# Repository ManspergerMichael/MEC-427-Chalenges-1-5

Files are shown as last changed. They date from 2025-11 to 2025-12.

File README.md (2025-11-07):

# MEC 427 — Smart Sensor and Actuator System (Challenges 1–3)

This repository contains the work for MEC 427 Smart Systems Challenges 1–3 using an Adafruit Circuit Playground Express (CPX) with CircuitPython. For the full design and schedule, see `Ch1,2,3/CombinedSmartSystemPlan.markdown`.

## Objective

Build and demonstrate a fluid control system using a 6-inch PVC end-cap tank suspended on a PVC tripod. Detect water level in a lower container using three CPX capacitive touch sensors (alligator clips) with a majority-vote scheme, and drive a 3D‑printed tube‑pinch valve using a TowerPro SG92R servo to prevent overflow.

## Challenge 1 — Fluid Level Sensor (Capacitive)

- **Location**: `Challenge_1/code.py`
- Use CPX capacitive touch (`touchio.TouchIn`) on A1 to sense water presence via an alligator-clip probe.
- Includes on-device visual calibration UI (NeoPixel bar + threshold marker) and saves threshold to `cal.txt`.
- Goal: Reliably detect when water reaches the probe depth.

## Challenge 2 — Voting Sensor System (Redundancy)

- **Location**: `Challenge_2/code.py`
- Expand to three probes on pads A1–A3, positioned at similar heights.
- Implement majority voting: "level reached" when ≥2 sensors exceed the threshold.
- Goal: Robust detection that tolerates a single sensor fault or noise.

## Challenge 3 — Smart Actuator System (Pinch Valve)

- 3D‑print a pinch‑valve mechanism and mount an SG92R servo to pinch 1/4" tubing.
- Wire servo: signal → A6, power → VOUT, ground → GND.
- Logic: On “level reached,” set `servo.angle = 90` to close the valve; provide a button (e.g., `button_a`) action to reset/open.

---

For detailed build notes, materials, timeline, and risks, see `Ch1,2,3/CombinedSmartSystemPlan.markdown`. The CPX runtime code lives in `Challenge_1/code.py`.

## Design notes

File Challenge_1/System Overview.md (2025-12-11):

# System Overview

## Introduction

The Liquid Level Sensor System is a mechatronics training platform designed to demonstrate the integration of sensors, controls, and user calibration in a process environment. Its primary function is to detect the liquid level in a container of water and provide visual feedback through onboard indicators.

## Hardware Architecture

The system is built around the **Adafruit Circuit Playground Express (CPX)**, which serves as the central controller. The CPX utilizes its capacitive touch sensor at pin **A1**, connected via a wired alligator clip secured to the rim of the container, to detect changes in capacitance caused by the presence of liquid. This sensing method allows the system to identify when the liquid reaches a defined level.d level.

## Power and Feedback

Power is supplied by a **3.7V battery**, ensuring portability and safe operation in laboratory settings. The CPX's **NeoPixel LEDs** provide real-time feedback and are also used during manual calibration. Calibration enables adjustment for environmental conditions (humidity, temperature, container material) and for different liquids with varying dielectric properties, ensuring reliable detection across multiple scenarios.enarios.

## System Integration

This system highlights the integration of hardware (CPX, sensors, battery), software (calibration routines, LED control), and process control concepts. It serves as a practical demonstration of how mechatronic systems combine sensing, computation, and actuation to achieve robust functionality in real-world applications.

---
## Sequential Function Chart

Controller Overview
The Adafruit Circuit Playground Express (CPX) serves as the central controller for the Liquid Level Sensor System. It integrates sensing, computation, and user interface functions into a single compact platform, enabling reliable detection and calibration of liquid levels.
The CPX is powered by a 3.7V rechargeable battery, providing portable operation and safe voltage levels for laboratory use. Its capacitive touch sensor at pin A1 is configured as the primary input, connected via an alligator clip to the rim of the container. This sensor detects changes in capacitance caused by the presence of liquid, allowing the controller to determine when the water reaches the defined level.
The CPX also incorporates NeoPixel LEDs and onboard controls, which serve as both output indicators and calibration tools. The LEDs provide immediate visual feedback of sensor status, while the onboard buttons allow manual adjustment of sensitivity to account for environmental conditions (humidity, temperature, container material) and variations in liquid properties. This ensures accurate and adaptable operation across different scenarios.
Internally, the CPX executes a control program written in CircuitPython which manages sensor input, calibration routines, and output display. The program is modular, allowing easy modification for expanded functionality, such as multi-level detection or integration with external actuators.
By combining sensing, processing, and feedback in one device, the CPX demonstrates the principles of mechatronic control: integration of hardware, software, and user interaction to achieve robust system performance.

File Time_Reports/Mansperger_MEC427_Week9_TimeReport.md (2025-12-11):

# 🛠️ MEC 427 Advanced Sensors and Actuators Challenges 1-5

---

## 📅 Date & Time
- **Report Date:** `12-01-2025`
- **Time Block:** `12-01 – 12-06`
- **Time Spent This Session:** `12 hours / 0 minutes`
- **Cumulative Time on Project:** `45 hours / 30 minutes`

---

## 📂 Project Overview
- **Project Title:**  `Challenge 4: Cable trolly, and Challenge 3: Water control system.`
- **Project Objective(s):**  
- `Design an actuator system that can traverse a steel tension cable. `
- **Current Phase:** `Completion`

---

## 🔧 Task / Activity Details
- **Module / Subsystem:**  `Challenge 4 Gantry motion control system Wiring and model design refinement`
- **Specific Task or Activity:**  
- **Time Spent on This Task:** `6 hours /  minutes`
- **% of Total Time:** `80%`
- **Resources Used:**  
  - **Hardware:**  
  - **Software:**  
  - **Tools:**  `Grok AI, Fusion 360.`
  - **Documentation:**  `Design Sketches CAD designs`
---
- **Module / Subsystem:**  `Challenge 3 Water control system coding and testing`
- **Specific Task or Activity:**  
- **Time Spent on This Task:** `2 hours / 30 minutes`
- **% of Total Time:** `50%`
- **Resources Used:**  
  - **Hardware:**  `Adafruit CPX, capacitive touch sensors, servo pinch valve, water tower model.`
  - **Software:**  `VsCode, CircuitPython.`
  - **Tools:**  `Copilot AI`
  - **Documentation:**  ` AI conversation, code files, test results.`

- ## Project Status Update:
- **Task/Module:** `Challenge 4 Gantry motion control system design`
- **Project Completion Status:** `90% complete`
- **Milestones Reached:**  ``CAD Model Updated to final design, STL files generated for 3D printing.`
- **Blockers or Issues:**  `Delays in 3D printing due to printer availability.`
- 
- **Task/Module:** `Challenge 3 Water control system coding and testing`
- **Project Completion Status:** `100% complete`
- **Milestones Reached:**  `Fine tuned the system to reliably control water flow based on sensor input.`
- **Blockers or Issues:**  `Fine-tuning the sensor calibration to avoid false readings.`

## 📦 Results & Deliverables
- **What Was Achieved:**  `Completed Challenge 4 Wiring and finished challenge 3.`
- **Artifacts Created:**  `CAD designs for cable trolly system. Code and test results for water control system.`
- **Validation / Testing Outcomes:**  `Water tower actuation tests show reliable operation with current calibration.`
- **Changes Made to Design or Approach:**  `GroK AI was used to assist in design ideation and STL generation with tinkercad.`

---

## 📜 Narrative & Observations
> _Use this section for detailed descriptions, reflections, and context. Include technical notes, emotional observations, and rationale for decisions._

- **Narrative Summary:**  `Challenge 3 was completed with successful unit testing of the software and functionality of the water control system. Challenge 4 design was refined and wiring schematics were developed, but physical assembly is pending due to 3D printing delays. Thinking of my workflow I can see the 'hobbyist' side of me wanting to get my hands on the physical parts. I did not spend enough time considering various aspects of system design. The carriage itself will work hypothetically,  things such as housing for electronics and the weight and distribution of components were not fully considered. Also I need to work on my documentation skills to better track changes and decisions made during the design process. Over the coming break I will go over my project assets and develop my overall workflow to be more efficient and effective.`

---

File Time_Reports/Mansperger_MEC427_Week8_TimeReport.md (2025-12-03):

# 🛠️ MEC 427 Advanced Sensors and Actuators Challenges 1-5

---

## 📅 Date & Time
- **Report Date:** `11-22-2025`
- **Time Block:** `11-17 – 11-22`
- **Time Spent This Session:** `8 hours / 30 minutes`
- **Cumulative Time on Project:** `33 hours / 30 minutes`

---

## 📂 Project Overview
- **Project Title:**  `Challenge 4: Cable trolly, and Challenge 3: Water control system.`
- **Project Objective(s):**  
- `Design an actuator system that can traverse a steel tension cable. `
- **Current Phase:** `Design Phase`

---

## 🔧 Task / Activity Details
- **Module / Subsystem:**  `Challenge 4 Gantry motion control system design`
- **Specific Task or Activity:**  
- **Time Spent on This Task:** `6 hours /  minutes`
- **% of Total Time:** `80%`
- **Resources Used:**  
  - **Hardware:**  
  - **Software:**  
  - **Tools:**  `Grok AI, Fusion 360.`
  - **Documentation:**  `Design Sketches CAD designs`
---
- **Module / Subsystem:**  `Challenge 3 Water control system coding and testing`
- **Specific Task or Activity:**  
- **Time Spent on This Task:** `2 hours / 30 minutes`
- **% of Total Time:** `50%`
- **Resources Used:**  
  - **Hardware:**  `Adafruit CPX, capacitive touch sensors, servo pinch valve, water tower model.`
  - **Software:**  `VsCode, CircuitPython.`
  - **Tools:**  `Copilot AI`
  - **Documentation:**  ` AI conversation.`

- ## Project Status Update:
- **Task/Module:** `Challenge 4 Gantry motion control system design`
- **Project Completion Status:** `75% complete`
- **Milestones Reached:**  `Finalized CAD design for gantry motion control system.`
- **Blockers or Issues:**  
- 
- **Task/Module:** `Challenge 3 Water control system coding and testing`
- **Project Completion Status:** `8% complete`
- **Milestones Reached:**  `System is able to read water levels and actuate the valve based on sensor input.`
- **Blockers or Issues:**  `Fine-tuning the sensor calibration to avoid false readings.`

## 📦 Results & Deliverables
- **What Was Achieved:**  `Completed Challenge 4 Design and finished the first phase of coding for challenge 3.`
- **Artifacts Created:**  `CAD designs for cable trolly system. Code and test results for water control system.`
- **Validation / Testing Outcomes:**  `Water tower actuation tests show reliable operation with current calibration.`
- **Changes Made to Design or Approach:**  `GroK AI was used to assist in design ideation and STL generation with tinkercad.`

---

## 📜 Narrative & Observations
> _Use this section for detailed descriptions, reflections, and context. Include technical notes, emotional observations, and rationale for decisions._

- **Narrative Summary:**  `Challenge 4 required several more iterations of design before I settled on the 'sandwich' concept. Using Grok AI to brainstorm design ideas and Fusion 360 for CAD modeling greatly expedited the process. The idea didn't really come together until after researching cable and zipline systems in industry applications. For Challenge 3,I hit the limitations of the CPX memory when implementing more features. Copilot was able to streamline the code and reduce memory usage significantly. Encountered power spikes when the servo actuated, which I mitigated by adding a separate power supply for the servo. Learning a lot about electronics, wiring, and power management. My lack of experience in engineering is a recurring challenge, but I'm making progress.`

---

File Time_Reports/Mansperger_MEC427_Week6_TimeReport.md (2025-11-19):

# 🛠️ MEC 427 Advanced Sensors and Actuators Challenges 1-5

---

## 📅 Date & Time
- **Report Date:** `11-08-2025`
- **Time Block:** `11-03 – 11-08`
- **Time Spent This Session:** `7 hours / minutes`
- **Cumulative Time on Project:** `21 hours / 30 minutes`

---

## 📂 Project Overview
- **Project Title:**  `Challenges 1-3: Smart Sensor and Actuator System`
- **Project Objective:**  `Create a smart fluid control system using level sensors and a servo-actuated pinch valve to control flow.`
- **Current Phase:** `Implementation Phase`

---

## 🔧 Task / Activity Details
- **Module / Subsystem:**  `Voting sensor system.`
- **Specific Task or Activity:**  
- **Time Spent on This Task:** `7 hours / minutes`
- **% of Total Time:** `100%`
- **Resources Used:**  
  - **Hardware:**  `Adafruit Circuit Playground Express (CPX), TowerPro SG92R servo, alligator clips, 1/4" aquarium tubing, 3D printer (PLA filament)`
  - **Software:**  `CircuitPython, VSCode IDE`
  - **Tools:**  `Copilot/Claude AI, Internet Research, Python.`
  - **Documentation:**  `Code files.`

---

## 📈 Progress Tracking
- **Task/Module:** `Challenge 1`
- **Project Completion Status:** `100% complete`
- **Milestones Reached:**  `Completed fluid level sensor with capacitive touch.`
- **Blockers or Issues:**  `Learning about calibration.`
- 
**Task/Module:** `Challenge 2`
- **Project Completion Status:** `80% complete`
- **Milestones Reached:**  `Sensor array prototype completed.`
- **Blockers or Issues:**  `Need to adapt the tower to hold multiple sensors securely.`
---

## 📦 Results & Deliverables
- **What Was Achieved:**  `Completed Challenge 1 and made significant progress on Challenge 2.`
- **Artifacts Created:**  `CircuitPython code for Challenges 1 and 2, sensor array prototype.`
- **Validation / Testing Outcomes:**  `Sensor can detect water level`
- **Changes Made to Design or Approach:**  

---

## 📜 Narrative & Observations
> _Use this section for detailed descriptions, reflections, and context. Include technical notes, emotional observations, and rationale for decisions._

- **Narrative Summary:**  `I made good progress on the software for the sensor and actuator system. In challenge 1 I added a calibration UI to help set the capacitive threshold for water detection. I found I need to adapt the tower to hold multiple sensors securely for challenge 2. Alligator clips are proving to be difficult. I also need a new work area as my desk dosen't have enough space for the full setup. and my cables are too short to arrange everything properly.`
- **Technical Notes:**  
- **Lessons Learned / Insights:**  
- **Emotional/Workflow Reflections (optional):**  

---

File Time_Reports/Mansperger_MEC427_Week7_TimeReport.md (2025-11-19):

# 🛠️ MEC 427 Advanced Sensors and Actuators Challenges 1-5

---

## 📅 Date & Time
- **Report Date:** `11-15-2025`
- **Time Block:** `11-10 – 11-15`
- **Time Spent This Session:** `3 hours / 30 minutes`
- **Cumulative Time on Project:** `25 hours / 0 minutes`

---

## 📂 Project Overview
- **Project Title:**  `Challenges 4 & 5: Gantry motion control system and Bead Sorting without controls perspective.`
- **Project Objective(s):**  
- `Design an actuator system that can traverse a steel tension cable. `
- `Conseptualize a bead sorting system that uses sensors and actuators to sort beads without using a controls perspective.`
- **Current Phase:** `Implementation Phase`

---

## 🔧 Task / Activity Details
- **Module / Subsystem:**  `Challenge 4 Gantry motion control system design`
- **Specific Task or Activity:**  
- **Time Spent on This Task:** `1 hours / 30 minutes`
- **% of Total Time:** `50%`
- **Resources Used:**  
  - **Hardware:**  
  - **Software:**  
  - **Tools:**  `Grok AI, Tinkercad, Internet research.`
  - **Documentation:**  `Design Sketches and AI generated STL.`
---
- **Module / Subsystem:**  `Challenge 5 Bead Sorting without controls perspective`
- **Specific Task or Activity:**  
- **Time Spent on This Task:** `2 hours / 0 minutes`
- **% of Total Time:** `50%`
- **Resources Used:**  
  - **Hardware:**  
  - **Software:**  
  - **Tools:**  `Grok AI, Knowledge course resources, Internet research.`
  - **Documentation:**  `Notes, sketches, AI conversation.`

- ## Project Status Update:
- **Task/Module:** `Challenge 4 Gantry motion control system design`
- **Project Completion Status:** `70% complete`
- **Milestones Reached:**  `Completed a conceptual design and prototype for gantry motion control system.`
- **Blockers or Issues:**  `A dentist appointment caused me to miss a comp-team session`
- 
- **Task/Module:** `Challenge 5 Bead Sorting without controls perspective`
- **Project Completion Status:** `100% complete`
- **Milestones Reached:**  `Completed a conceptual design for bead sorting system.`
- **Blockers or Issues:**  `Not thinking about controls made it challenging to conceptualize the sorting mechanism.`

## 📦 Results & Deliverables
- **What Was Achieved:**  `Completed Challenge 5 and made significant progress on Challenge 4.`
- **Artifacts Created:**  `Conseptusual designs and AI generated STL files for gantry system. Sketches and notes for bead sorting system.`
- **Validation / Testing Outcomes:**  `N/A`
- **Changes Made to Design or Approach:**  `GroK AI was used to assist in design ideation and STL generation with tinkercad.`

---

## 📜 Narrative & Observations
> _Use this section for detailed descriptions, reflections, and context. Include technical notes, emotional observations, and rationale for decisions._

- **Narrative Summary:**  `Challenge 2: I didn't consider mounting the sensors on the water tower during my initial design, I compensated by using the CPX kit's alligator clips as extension wires and fixed them to the legs of the tower using tape. The sensor probes hang down into the lower container to detect water level. Callibration was a learning process, assisted by Copilot AI. The CPX capacitive touch sensors are rather sensitive and the wire insulation is suboptimal. An issue where the sensor readings would reverse polarity when the probes touched water was resolved by implementing a dual-threshold detection system, accounting for both increases and decreases in capacitance. This approach improved reliability significantly. The voting system was implemented successfully, allowing the system to function correctly even if one sensor failed or provided erroneous readings.`
- **Narrative Summary:**  `Challenge 4: I conceptualized a Tri-wheel gantry motion control system that uses a motor to move an actuator along a steel tension cable. I used Grok AI to generate design sketches and STL files for the gantry components. The design includes a motor, pulley system, and guide rails to ensure smooth movement along the cable.`
- - **Narrative Summary:**  `Challenge 5: A design session with Grok AI and my notes from the knowledge course. I conceptualized a bead sorting system where the blue and yellow beads sorted by color on a single track that splits into two paths. The beads pass through photoelectric sensors that detect their color. When a blue bead is detected, a small servo actuator diverts it to the left path, while yellow beads continue straight. This design avoids complex control systems by using simple sensor-actuator pairs for sorting. This consept can be scaled up to include more colors and sorting paths or multiple tracks for volume sorting.`

---

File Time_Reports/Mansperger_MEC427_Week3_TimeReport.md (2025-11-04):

# 🛠️ MEC 427 Advanced Sensors and Actuators Challenges 1-5

---

## 📅 Date & Time
- **Report Date:** `10-18-2025`
- **Time Block:** `10-13 – 10-18`
- **Time Spent This Session:** `5 hours / minutes`
- **Cumulative Time on Project:** `9 hours / minutes`

---

## 📂 Project Overview
- **Project Title:**  `MEC 427 Advanced Sensors and Actuators Challenges 1-5`
- **Project Objective:**  `Complete Challenges 1-5 for MEC 427 Advanced Sensors and Actuators course.`
- **Current Phase:** `Sketching and Planning Phase`

---

## 🔧 Task / Activity Details
- **Module / Subsystem:**  `Development Plans research and documentation`
- **Specific Task or Activity:**  `Planning and research for Challenges 1-5`
- **Time Spent on This Task:** `5 hours`
- **% of Total Time:** `100%`
- **Resources Used:**  
  - **Hardware:**  
  - **Software:**  
  - **Tools:**  `Internet resources, Grok AI, VScode, Markdown, Copilot`
  - **Documentation:**  

---

## 📈 Progress Tracking
- **Task/Module Completion Status:** `85% complete (estimated)`
- **Project Completion Status:** `15% complete (estimated)`
- **Milestones Reached:**  `Development Plans drafted for Challenges 1-5`
- **Blockers or Issues:**  
- **Next Steps / Planned Actions:**  `Build water tank prototype for Challenge 1-3, start developing code for CPX microcontroller, build water tower fixture.`

---

## 📦 Results & Deliverables
- **What Was Achieved:** `3 development plans drafted for Challenges 1-5`
- **Artifacts Created:**  `Development plan documents`
- **Validation / Testing Outcomes:**  
- **Changes Made to Design or Approach:**  

---

## 📜 Narrative & Observations
> _Use this section for detailed descriptions, reflections, and context. Include technical notes, emotional observations, and rationale for decisions._

- **Narrative Summary:** 
- `I reviewed my Adafruit CPX microcontroller kit and found that it came with all the necessary components to build a smart sensor/actuator system. I worked with Grok AI to brainstorm ideas for my system. I will be creating a water tower and container system were capacitive sensors will detect the water level in the container and a servo motor controlled pinch valve will stop the water flow when water reaches a certain level in the container. The water "tower" will be made of PVC pipes with rubber tubing fixed to a hole at the bottom of the tank. The pinch valve I can design with CAD or I could find an existing design I can modify and print. Construction of the tower should be simple. I set up a Python development environment using VSCode and installed the necessary libraries to program the CPX. I finished the initial development plans for Challenges 1-5, challenges 4 and 5 I will need to do more research/sketching on. I'll need to ask if a tension wire fixture will be provided making one might be an issue at home. The CPX has built in accelerometer I can use as a balance sensor. The actuator will need more thought.`
- **Technical Notes:** ''
- **Lessons Learned / Insights:** `Marveling a bit at how productive AI tools can be for brainstorming, planning, and documentation. Feeling optimistic about the project direction so far.`

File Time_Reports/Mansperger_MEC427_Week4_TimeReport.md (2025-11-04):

# 🛠️ MEC 427 Advanced Sensors and Actuators Challenges 1-5

---

## 📅 Date & Time
- **Report Date:** `10-25-2025`
- **Time Block:** `10-20 – 10-25`
- **Time Spent This Session:** `3 hours / 30 minutes`
- **Cumulative Time on Project:** `12 hours / 30 minutes`

---

## 📂 Project Overview
- **Project Title:**  `Challenge 1 - 3 Water Level Sensor and Actuator System`
- **Project Objective:**  `Assemble and program a water level sensor and actuator system using the Adafruit CPX microcontroller to control water flow based on sensor input.`
- **Current Phase:** `Setup Phase`

---

## 🔧 Task / Activity Details
- **Module / Subsystem:**  `Construction of water tower`
- **Specific Task or Activity:** `Assemble water tower structure using PVC pipes and rubber tubing` 
- **Time Spent on This Task:** `3 hours / 30 minutes`
- **% of Total Time:** `100%`
- **Resources Used:**  
  - **Hardware:**  `PVC pipe, rubber tubing, Adafruit CPX microcontroller, capasitive sensors, servo motor, 3D printed pinch valve`
  - **Software:**  
  - **Tools:**  `3D printer`
  - **Documentation:**  

---

## 📈 Progress Tracking
- **Task/Module Completion Status:** `e.g., 15% complete`
- **Project Completion Status:** `15% complete`
- **Milestones Reached:**  `Gatered all materials, assembled water tower structure`
- **Blockers or Issues:**  `Pinch valve design needs refinement to ensure proper sealing`
- **Next Steps / Planned Actions:**  `Refine pinch valve design and reprint, begin programming CPX microcontroller to read sensor data and control servo motor`

---

## 📦 Results & Deliverables
- **What Was Achieved:**  `Assembled the water tower and tested prototype of pinch valve`
- **Artifacts Created:**  `3D printed pinch valve prototype, water tower assembly`
- **Validation / Testing Outcomes:**  
- **Changes Made to Design or Approach:**  

---

## 📜 Narrative & Observations
> _Use this section for detailed descriptions, reflections, and context. Include technical notes, emotional observations, and rationale for decisions._

- **Narrative Summary:**  `Furstrated with the delay in needing to reprint the pinch valve. But the tower should work for my project. Hoped to get to programming this week. Will look over challenge 4 and 5 while waiting for the print to finish.`
- **Technical Notes:**  
- **Lessons Learned / Insights:**  
- **Emotional/Workflow Reflections (optional):**  

---

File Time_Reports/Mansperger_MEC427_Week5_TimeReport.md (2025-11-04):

# 🛠️ MEC 427 Advanced Sensors and Actuators Challenges 1-5

---

## 📅 Date & Time
- **Report Date:** `11-01-2025`
- **Time Block:** `10-27 – 11-01`
- **Time Spent This Session:** `2 hours / minutes`
- **Cumulative Time on Project:** `14 hours / 30 minutes`

---

## 📂 Project Overview
- **Project Title:**  `Challenge 4 - Development Plans for Advanced Sensors and Actuators`
- **Project Objective:**  `Create Initial Development Plans`
- **Current Phase:** `Sketching Phase`

---

## 🔧 Task / Activity Details
- **Module / Subsystem:**  `Development Plans`
- **Specific Task or Activity:**  
- **Time Spent on This Task:** `2 hours / minutes`
- **% of Total Time:** `100%`
- **Resources Used:**  
  - **Hardware:**  
  - **Software:**  
  - **Tools:**  `Grok AI, Internet Research`
  - **Documentation:**  `Concept sketches for actuator`

---

## 📈 Progress Tracking
- **Task/Module Completion Status:** `50% complete`
- **Project Completion Status:** `15% complete`
- **Milestones Reached:**  
- **Blockers or Issues:**  `Several internet services were down. Stopped by need of dentist appointment.`
- **Next Steps / Planned Actions:**  `Complete development plans and begin prototyping actuator designs.`

---

## 📦 Results & Deliverables
- **What Was Achieved:**  
- **Artifacts Created:**  `Concept sketches for actuator`
- **Validation / Testing Outcomes:**  
- **Changes Made to Design or Approach:**  

---

## 📜 Narrative & Observations
> _Use this section for detailed descriptions, reflections, and context. Include technical notes, emotional observations, and rationale for decisions._

- **Narrative Summary:**  `AWS and other internet services were down for much of the week, along with my sudden tooth pain that required a dentist visit. I was able to make some progress on the development plans. Next week I will aim to make up for lost time. 12 hours in lab work next week.`
- **Technical Notes:**  
- **Lessons Learned / Insights:**  
- **Emotional/Workflow Reflections (optional):**  

---

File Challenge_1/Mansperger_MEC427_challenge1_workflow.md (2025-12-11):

# Smart Sensor Development Workflow  
**Assignment: Challenge 1 – Smart Sensor**

---

## 1. Application Description  
The smart sensor system is designed to **detect when liquid reaches a predefined level in a container**.  

- **Function**: The sensor continuously monitors the liquid level and identifies when the set threshold is reached.  
- **Conditions**: Upon detecting liquid at the target level, the sensor outputs a **HIGH signal** to the microcontroller for processing.  
- **Feedback**: The system provides a clear indication (e.g., LED, buzzer, or digital flag) that the container has reached the fill level.  
  - **Conditions**: The system will continue sending a **HIGH signal** as long as liquid is detected at the sensor point.  

---

## 2. Task Description  
- Develop a sensor system capable of accurately detecting liquid levels.  
- Integrate the sensor with a **microcontroller** for real-time monitoring and data acquisition.  
- Implement calibration routines to account for different liquid properties (density, conductivity).  
- Provide user-defined alarms for high/low levels.  
- Validate performance through testing in simulated tank conditions.  

---

## 3. Focus Area  

### Work Piece  
A **water tower model** was chosen as the work piece to develop the fill sensor because its construction and function are simple and effective for demonstration. The setup consists of **two containers**, with one suspended above the other. A hose at the bottom of the top container allows water to flow downward, while sensors are mounted on the rim of the bottom container to detect the liquid level.  

### Mechanism  
The sensor is mounted on the lower container and wired directly to a **microcontroller** for real-time monitoring.  
- **Potential Risks**:  
  - **Water damage to the microcontroller** due to proximity to the liquid environment.  
  - **Wear or damage to the sensor** if it comes into direct contact with water or other liquids.  
- **Mitigation Strategies**:  
  - Use waterproof housings or protective enclosures for the microcontroller.  
  - Employ non-contact sensor technologies (e.g., ultrasonic or capacitive) to reduce wear and prevent liquid exposure.  
  - Position wiring and electronics above the liquid line to minimize risk.  

---

## 4. Risk Assessment  

| Risk | Likelihood | Impact | Mitigation Strategy |
|---|---|---|---|
| Sensor fouling due to residue buildup | High | Medium | Use self-cleaning or non-contact sensors |
| Incorrect readings from foam/turbulence | Medium | High | Apply filtering algorithms and sensor shielding |
| Electrical failure in wet environments | Low | High | Waterproof housing and redundant wiring |
| Calibration drift | Medium | Medium | Regular calibration and automated self-check routines |
| Power instability | Medium | Medium | Use regulated power sources and backup batteries |

---

## 5. Definition of Application  
The smart sensor application is defined as a **liquid level detection system** that uses capacitive sensing technology to monitor when tap water reaches a predefined fill level in a container. The system is powered by a microcontroller and designed for reliable operation in controlled indoor environments.  

- **Available Power**: The system is powered by an **Adafruit Circuit Playground Express microcontroller kit**, with support from a **3.7V battery pack** for portable operation.  
- **Output Requirements**: Capacitive touch sensors, connected via **wired alligator clips** mounted on the rim of the bottom container, provide detection signals and calibration data. Signal conditioning is implemented to reduce false positives caused by disturbances such as waves or splashes contacting the sensor head.  
- **Target Object**: The sensor is calibrated to detect **tap water** as the monitored liquid.  
- **Environmental Conditions**: The system is intended for use in an **indoor environment at room temperature**, ensuring stable sensor performance and minimizing environmental interference.  

---

## 6. Sensor Technologies  
For this project, the **Adafruit Circuit Playground Express (CPX) kit** was selected as the primary development platform. The CPX was recommended due to its versatility and integrated features that support rapid prototyping of smart sensor applications.  

- **Capacitive Touch Sensors**: Used to detect the presence of liquid at the container rim. These sensors provide reliable input signals and can be calibrated to minimize false positives caused by splashes or waves.  
- **LED Lights**: Integrated LEDs serve as immediate visual indicators, signaling when the liquid has reached the predefined fill level.  
- **Buttons for Controls**: Onboard buttons allow for manual calibration, reset, or user-defined input during testing and development.  
- **Microcontroller Integration**: The CPX’s built-in microcontroller processes sensor signals in real time, enabling accurate monitoring and feedback.  
- **Expandable Features**: The CPX supports additional modules and external connections, making it adaptable for future enhancements or alternative sensing methods.  

This combination of features makes the CPX kit an effective choice for developing and testing the liquid level smart sensor, while also simplifying the workflow by reducing the need for external components.

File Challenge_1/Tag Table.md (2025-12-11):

| STEP | Component | Address |
|---|---|---|
| 1 | Water Hose Flow | | |
| 2 | Capacitive Touch Sensor | A1 |

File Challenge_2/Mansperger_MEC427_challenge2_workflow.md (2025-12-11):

# Technical Data Package  
**Assignment: Challenge 2 – Smart Sensor**

---

## 1. Application Description  
The smart sensor system is designed to **detect when liquid reaches a predefined level in a container** using a **voting sensor array**.  

- **Function**: Three capacitive touch sensors are mounted at the same water level. Each sensor independently detects liquid presence.  
- **Conditions**: When liquid reaches the sensor line, each sensor outputs a **HIGH signal** to the microcontroller.  
- **Feedback**: The microcontroller applies a **majority voting algorithm**. If at least two sensors detect liquid, the system confirms the fill level and signals accordingly.  
  - **Conditions**: The system continues to send a HIGH signal as long as the majority of sensors detect liquid.  

---

## 2. Task Description  
- Develop a sensor system with **three capacitive touch sensors** connected to the Adafruit CPX microcontroller.  
- Implement a **voting algorithm** to determine liquid detection based on majority agreement.  
- Provide feedback through LEDs or buzzers when the fill level is confirmed.  
- Validate performance by testing with tap water in a controlled water tower model.  
- Compare reliability against single-sensor detection.  

---

## 3. Focus Area  

### Work Piece  
The **water tower model** remains the chosen work piece. Three capacitive sensors are mounted at the same height on the rim of the bottom container to detect liquid presence at the fill level.  

### Mechanism  
The sensors are wired to the CPX microcontroller, which processes their signals and applies a voting algorithm.  
- **Potential Risks**:  
  - **Water damage to the microcontroller** due to proximity to liquid.  
  - **Sensor wear or damage** if sensors touch the liquid directly.  
  - **Disagreement between sensors** due to noise or calibration drift.  
- **Mitigation Strategies**:  
  - Waterproof housing for the CPX.  
  - Protective coatings or non-contact sensor placement.  
  - Regular calibration and signal conditioning to reduce false positives.  
  - Voting logic ensures reliability even if one sensor fails.  

---

## 4. Risk Assessment  

| Risk | Likelihood | Impact | Mitigation Strategy |
|---|---|---|---|
| Incorrect readings from foam/turbulence | Medium | High | Apply filtering algorithms and sensor shielding |
| Calibration drift across sensors | Medium | Medium | Regular calibration and automated self-check routines |
| Sensor disagreement (false positives/negatives) | Medium | Medium | Majority voting algorithm ensures reliable detection |
| Power instability | Medium | Medium | Use regulated power sources and backup batteries |

---

## 5. Definition of Application  
The smart sensor application is defined as a **redundant liquid level detection system** that uses a voting sensor array to improve reliability. By requiring majority agreement among three capacitive sensors, the system reduces false positives and ensures robust detection.  

- **Available Power**: Powered by the **Adafruit Circuit Playground Express kit**, with a **3.7V battery pack** for portable operation.  
- **Output Requirements**: Three capacitive touch sensors connected via alligator clips provide detection signals. The CPX applies voting logic and outputs confirmation signals through LEDs or buzzers.  
- **Target Object**: The system is calibrated to detect **tap water**.  
- **Environmental Conditions**: Designed for **indoor use at room temperature**, ensuring stable sensor performance.  

---

## 6. Sensor Technologies  
The **Adafruit Circuit Playground Express (CPX) kit** was selected as the development platform due to its versatility and integrated features.  

- **Capacitive Touch Sensors**: Three sensors detect liquid presence at the same level, providing redundant input for voting logic.  
- **LED Lights**: Integrated LEDs indicate when the majority of sensors confirm the fill level.  
- **Buttons for Controls**: Onboard buttons allow calibration, reset, or manual input during testing.  
- **Microcontroller Integration**: The CPX processes signals from all three sensors in real time, applying majority voting to ensure reliable detection.  
- **Expandable Features**: The CPX supports additional modules and external connections, making it adaptable for future enhancements.  

This combination of features makes the CPX kit an effective choice for developing and testing a **voting sensor array** for liquid level detection.

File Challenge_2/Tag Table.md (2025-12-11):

| STEP | Component | Address |
|---|---|---|
| 1 | Water Flow | | |
| 2 | Capacitive Touch Sensor | A1 |
| 2 | Capacitive Touch Sensor | A3 |
| 2 | Capacitive Touch Sensor | A5 |

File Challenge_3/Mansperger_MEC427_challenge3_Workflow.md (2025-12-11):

# Smart Actuator Development Workflow  
**Assignment: Challenge 3 – Smart Actuator**

---

## 1. Application Description  
The smart actuator system is designed to **control water flow between two containers** using a servo-driven pinch valve.  

- **Function**: A Tower Pro SG92R micro servo, wired to the Adafruit CPX, actuates a 3D-printed pinch valve.  
- **Conditions**: The valve is mounted on a leg of the tower between the upper and lower containers. The hose passes through the valve, allowing the servo to open or close water flow.  
- **Feedback**: The actuator responds to sensor signals from the lower container, enabling automated control of water transfer.  

---

## 2. Task Description  
- Integrate a **Tower Pro SG92R micro servo** with the Adafruit CPX microcontroller.  
- Mount the servo into a **3D-printed pinch valve** for mechanical actuation.  
- Position the valve between the upper and lower containers, with the hose routed through it.  
- Link actuator control to sensor feedback from the lower container.  
- Validate performance by testing water flow regulation under different sensor conditions.  

---

## 3. Focus Area  

### Work Piece  
The **water tower model** remains the chosen work piece. The pinch valve is mounted on a tower leg between the upper and lower containers, with the hose routed through the valve to the lower container where sensors are mounted.  

### Mechanism  
The servo rotates to compress or release the hose inside the pinch valve, controlling water flow.  
- **Potential Risks**:  
  - **Servo wear** from repeated actuation.  
  - **Valve misalignment** causing incomplete closure or leakage.  
  - **Water exposure** to servo or electronics.  
- **Mitigation Strategies**:  
  - Use durable servo mounts and limit actuation cycles.  
  - Ensure precise 3D printing and alignment of the valve.  
  - Apply waterproofing or protective housing for electronics.  

---

## 4. Risk Assessment  

| Risk | Likelihood | Impact | Mitigation Strategy |
|---|---|---|---|
| Servo wear from repeated cycles | Medium | Medium | Limit duty cycles, use robust mounting |
| Valve misalignment or leakage | Medium | High | Precision 3D printing and calibration |
| Water exposure to servo/electronics | Low | High | Waterproof housing and protective placement |
| Power instability | Medium | Medium | Use regulated power sources and backup batteries |

---

## 5. Definition of Application  
The smart actuator application is defined as a **servo-controlled pinch valve system** that regulates water flow between two containers based on sensor feedback.  

- **Available Power**: Powered by the **Adafruit Circuit Playground Express kit** with a **3.7V battery pack**.  
- **Output Requirements**: The Tower Pro SG92R servo actuates the pinch valve to open or close water flow. Control signals are processed by the CPX based on sensor input.  
- **Target Object**: Tap water flowing through the hose between containers.  
- **Environmental Conditions**: Designed for **indoor use at room temperature**, ensuring stable actuator performance.  

---

## 6. Actuator Technologies  
For this project, the **Tower Pro SG92R micro servo** was selected as the actuator due to its compatibility with the CPX and suitability for small-scale mechanical control.  

- **Micro Servo (SG92R)**: Provides rotational motion to actuate the pinch valve.  
- **3D-Printed Pinch Valve**: Converts servo rotation into hose compression, regulating water flow.  
- **Microcontroller Integration (CPX)**: Processes sensor signals and drives the servo accordingly.  
- **LED/Feedback Indicators**: CPX LEDs can signal valve state (open/closed).  
- **Expandable Features**: The system can be extended to include multiple valves or automated flow control routines.  

This combination of servo actuation and CPX integration makes the system an effective demonstration of smart actuator control in a liquid transfer application.

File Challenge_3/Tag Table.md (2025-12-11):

| STEP | Component | Address |
|---|---|---|
| 1 | Water Flow | |
| 2 | Capacitive Touch Sensor | A1 |
| 2 | Capacitive Touch Sensor | A3 |
| 2 | Capacitive Touch Sensor | A5 |
| 3 | SG92R Servo Pinch Valve | A6 |

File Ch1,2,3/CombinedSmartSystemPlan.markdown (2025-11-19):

# Combined Smart Sensor and Actuator Development Plan for Sensors and Actuators Class

## Objective

Build and demonstrate a fluid control system using a 6-inch PVC end cap tank suspended by a 1/2-inch PVC pipe tripod, with water level detection via three CPX capacitive touch sensors using alligator clips, a voting system for reliability, and a 3D-printed tube-pinch valve controlled by a TowerPro SG92R servo to prevent overflow. Smart features are to be determined (TBD).

## Project Overview

- **Setup**: A 6-inch Schedule 40 PVC end cap (~711-1184 mL, ~1.5-2.5 inch depth) as the tank, suspended 6-12 inches above a lower container (e.g., 500-1000 mL cup) via a tripod made of 1/2-inch PVC pipes. Water flows through a 1/4-inch tube, controlled by a servo-driven 3D-printed pinch valve.
- **Challenge 1 (Fluid Level Sensor)**: Use CPX capacitive touch pads (A1-A3) with alligator clips to detect water level in the lower container.
- **Challenge 2 (Voting Sensor System)**: Implement three capacitive sensors (alligator clips) with majority voting (≥2 sensors detect water) for robust detection.
- **Challenge 3 (Smart Actuator System)**: Use an SG92R servo to close a 3D-printed pinch valve when the voting system triggers, stopping water flow.
- **Smart Features**: TBD.
- **Materials**:
  - **Tank**: 6-inch Schedule 40 PVC end cap.
  - **Tripod**: Three 2.5-foot 1/2-inch Schedule 40 PVC pipes, one 3/4-inch PVC tee, zip ties.
  - **Valve**: 1/4-inch aquarium tubing, SG92R servo (from CPX kit), 3D-printed pinch mechanism (PLA).
  - **Sensors**: Three alligator clips (from CPX kit) for capacitive probes, electrical tape/heat-shrink for insulation.
  - **Other**: Silicone sealant, jumper wires (from CPX kit).
- **Toolset**: CircuitPython on CPX (Mu editor), drill, hacksaw, 3D printer (school/library).
- **Deliverable**: Working prototype, CircuitPython code, demo video/report addressing all challenges, and analysis of system performance.

## Development Plan

### Step 1: Build Fluid Level Sensor (Challenge 1, 2-3 Days)

- **Task**: Create a single capacitive water level sensor.
  - Attach an alligator clip to CPX pad A1, with the metal jaw positioned in the lower container.
  - Insulate clip jaw partially with electrical tape, leaving ~0.5 cm² exposed for water contact.
  - Program in CircuitPython: Use `touchio.TouchIn` to read capacitance, set threshold (~1000, adjust via testing) for water detection.
  - Test: Submerge clip in water; use CPX NeoPixels and serial output for feedback.
- **Milestone**: Code detecting water level reliably, logged via serial monitor.

### Step 2: Implement Voting Sensor System (Challenge 2, 3-4 Days)

- **Task**: Expand to three capacitive sensors for voting.
  - Attach alligator clips to CPX pads A1-A3, placed at similar heights in the lower container for redundancy.
  - Insulate each clip’s jaw to prevent shorting; secure to container with tape/3D-printed holder.
  - Program voting logic: If ≥2 clips exceed threshold, set “level reached” flag.
  - Test faults: Disconnect one clip to ensure voting ignores it.
- **Milestone**: Code and hardware triggering "level reached" via majority vote, with NeoPixel feedback.

### Step 3: Build and Integrate 3D-Printed Pinch Valve (Challenge 3, 3-4 Days)

- **Task**: Construct tank and valve, integrate with sensors.
  - **Tank Setup**:
    - Drill 1/4-inch hole in side of 6-inch PVC end cap (~0.5 inches from bottom).
    - Attach 1/4-inch aquarium tubing with silicone sealant (cure 24 hours).
    - Drill two 1/8-inch holes in cap’s rim (above waterline) for zip tie suspension.
  - **Tripod**:
    - Cut three 2.5-foot 1/2-inch PVC pipes; join in 3/4-inch tee (friction fit or tape).
    - Suspend end cap from tee with zip ties, ~6-12 inches above lower container.
  - **Pinch Valve**:
    - 3D-print a bracket (30x20x5 mm, with 2 mm holes for SG92R screws) and pinch arm (20-30 mm, slots for servo horn and tube) in PLA (Tinkercad or Thingiverse ID 4530241, modified).
    - Mount SG92R on end cap near outlet (glue/screws); attach arm to servo horn.
    - Route tubing through arm’s slot; servo rotates to 90° to pinch tube shut.
    - Wire SG92R: signal to A6, power to VOUT, ground to GND.
  - **Program**: When voting flag is true, set `servo.angle = 90` to close valve; reset to 0° via CPX button (e.g., button_a).
- **Milestone**: Prototype where sensors trigger servo to pinch tube, stopping flow.

### Step 4: Test and Validate System (2-3 Days)

- **Task**: Run end-to-end tests.
  - Scenarios: Normal fill (valve closes on detection), single sensor fault (voting handles it), low/high water starts.
  - Measure: Detection accuracy (>95%), response time (<1s), voting reliability.
  - Visualize: Use NeoPixels for status; log data via serial.
  - Debug: Adjust sensor thresholds, reinforce 3D-printed arm if needed.
- **Milestone**: Demo video showing system preventing overflow in multiple trials.

### Step 5: Analyze, Optimize, and Document (2-3 Days)

- **Task**: Evaluate and refine.
  - Analyze: Voting effectiveness, servo reliability, system performance.
  - Optimize: Tune threshold, adjust 3D print for tighter pinch.
  - Document: Report with diagrams, code, results, and challenge alignment.
  - Presentation: 5-7 min demo with prototype video.
- **Milestone**: Final report and presentation slides.

## Timeline

- **Total Duration**: 12-17 days.
- **Week 1**: Steps 1-2 (Sensors and voting).
- **Week 2**: Steps 3-4 (Valve, tripod, testing).
- **Week 3 (if needed)**: Step 5 (Analysis and docs).
- **Key Deadline**: Align with class submission.

## Resources

- **Hardware**: Adafruit CPX, SG92R servo (from kit), 6-inch PVC end cap, 1/2-inch PVC pipes, 3/4-inch tee, aquarium tubing, zip ties, silicone, alligator clips (from kit), electrical tape.
- **Software**: CircuitPython (adafruit.com), Mu editor.
- **3D Printing**: Tinkercad for design; PLA filament at school makerspace.
- **References**:
  - CPX Guide: learn.adafruit.com/adafruit-circuit-playground-express.
  - Servo Tutorial: learn.adafruit.com/adafruit-circuit-playground-express/circuitpython-servo.
  - Pinch Valve STL: thingiverse.com/thing:4530241.
  - Capacitive Sensing: learn.adafruit.com/circuitpython-essentials/circuitpython-capacitive-touch.
- **Environment**: Workbench, computer, 3D printer access.

## Risks and Mitigation

- **Risk**: Capacitive clips misfire (e.g., humidity, shorting).
  - **Mitigation**: Insulate jaws with tape/heat-shrink, calibrate thresholds, space clips apart.
- **Risk**: SG92R lacks torque to pinch tube.
  - **Mitigation**: Use soft 1/4-inch tubing, test 3D-printed arm strength.
- **Risk**: Water leaks from end cap.
  - **Mitigation**: Seal thoroughly with silicone, test with small volumes.
- **Risk**: Clip movement causes false readings.
  - **Mitigation**: Secure with tape or 3D-printed holder.

## Success Criteria

- Prototype fills container and stops via servo-driven pinch valve on level detection.
- Voting system handles single-sensor faults without false closure.
- Report addresses all challenges with code, demo, and performance analysis.
- Safe, DIY build with accessible materials.

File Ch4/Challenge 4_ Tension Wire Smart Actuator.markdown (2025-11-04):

# Challenge 4: Tension Wire Smart Actuator

This development plan outlines the design, construction, and testing of a smart actuator for Challenge 4, utilizing the Adafruit Circuit Playground Express (CPX) kit as the core microcontroller. The actuator will traverse a school-supplied tensioned steel cable, embodying Industry 4.0 principles of scalability, transportability, and interconnectivity. The plan leverages the CPX's built-in sensors (accelerometer, light/proximity), NeoPixels, and CircuitPython for rapid prototyping, with additional components for motor control and power. The timeline spans 4-6 weeks, focusing on mechatronic integration and iterative testing.

## Phase 1: Research and Planning (Week 1)
- **Define Objectives**: Build a smart actuator to move autonomously along a tensioned steel cable (1-2 meters) from one end to the other, demonstrating:
  - Scalability: Design replicable for multiple actuators.
  - Transportability: Lightweight, modular for easy relocation.
  - Interconnectivity: Interfaces with external systems via wired or wireless protocols.
- **Research Key Concepts**:
  - CPX Capabilities: Utilize onboard accelerometer for balance, light sensor for end-point detection, and I2C/SPI for add-ons.
  - Power Management: Leverage CPX’s low power draw (~20mA idle) with a LiPo battery and sleep modes.
  - UI: Use CPX’s USB for serial monitoring or a basic Python-based dashboard via Mu Editor.
  - Cable Traversal: Explore wheeled grippers or rollers for movement, considering cable tension and friction.
  - PAC Systems: Model programmable automation controller logic with CPX’s CircuitPython.
- **Brainstorm Design**: Sketch a compact actuator with CPX mounted centrally in a 3D-printed chassis, integrating a motor and rollers.
- **Milestone**: Requirements document with CPX pinout mapping (e.g., A1-A7 for sensors/motor).

## Phase 2: Design and Prototyping (Weeks 1-2)
- **Mechanical Design**:
  - Cable Setup: Use school-supplied steel cable (2-4mm diameter) tensioned with turnbuckles.
  - Actuator Body: Design a 3D-printed chassis (school printer/filament) to house CPX, motor, and cable-gripping wheels (e.g., 3D-printed with rubber O-rings).
  - Sensors: Rely on CPX’s accelerometer and light sensor; add limit switches for end-of-line detection if needed.
- **Electrical and Power Design**:
  - Power Management: Connect a LiPo battery (3.7V 500mAh, JST connector) to CPX’s JST port. Code sleep modes for efficiency (target: 15+ traversals per charge).
  - Microcontroller: Use CPX with CircuitPython for PAC-like logic and control.
- **Software and Integration**:
  - Integration Parameters: Enable wired interconnectivity via CPX’s USB; consider a Bluetooth module (e.g., HC-05) for wireless scalability.
  - UI Development: Start with serial output in Mu Editor for position and battery monitoring (via analog pin voltage divider). Optionally, develop a web UI via Bluetooth.
- **Prototype Assembly**: 3D-print initial chassis, wire CPX to a micro DC motor (e.g., N20 geared), and test on a short cable segment.
- **Milestone**: CAD files for printing; initial CPX code for motor control.

## Phase 3: Building and Implementation (Weeks 2-3)
- **Construct the Actuator**:
  - Mechanical Assembly: Print and fit chassis around CPX. Attach motor-driven wheels to grip cable; use accelerometer for tilt detection.
  - Electrical Wiring: Connect CPX to motor (via transistor or driver for current handling), battery, and optional sensors. Test on school-supplied cable.
  - Power Optimization: Implement PWM motor control and sparse sensor polling in CircuitPython.
- **Integrate Systems**:
  - Interconnectivity: Simulate Industry 4.0 by sending data (e.g., JSON over serial) to a laptop or another CPX.
  - UI Integration: Use NeoPixels for status (e.g., green for moving, red for low battery) and serial logs for monitoring.
- **Iterate Based on Feedback**: Bench-test for cable grip and vibration; refine 3D print tolerances.
- **Milestone**: Operational prototype traversing a 0.5m cable section.

## Phase 4: Testing and Evaluation (Weeks 3-4)
- **Functional Testing**:
  - Movement: Verify end-to-end traversal on full cable length. Measure speed, accuracy, and repeatability.
  - Power Management: Log consumption via CPX (target: 15+ traversals). Test under varying loads.
  - Integration: Validate data exchange with external systems (e.g., low-latency command response).
  - UI: Ensure serial/NeoPixel interface is intuitive; gather usability feedback.
- **Performance Evaluation**:
  - Industry 4.0 Metrics:
    - Scalability: Assess adaptability for longer cables or multiple actuators.
    - Transportability: Evaluate weight (<500g target) and ease of disassembly.
    - Interconnectivity: Measure data latency and reliability.
  - Quantitative: Log traversal time, energy use, and errors via CPX’s CSV library.
  - Qualitative: Document strengths (e.g., CPX modularity) and weaknesses (e.g., motor torque limits).
- **Edge Case Testing**: Program CPX for auto-stop on accelerometer-detected falls or low battery.
- **Milestone**: Test report with CPX-logged graphs (e.g., speed vs. power).

## Phase 5: Documentation and Reflection (Weeks 4-5, if extended)
- **Compile Results**: Include CPX code, wiring diagrams, 3D print files, and test data.
- **Reflect on Learnings**: Highlight CPX’s role in simplifying PAC-like control and Industry 4.0 integration.
- **Presentation Prep**: Create demo video of traversal and slides emphasizing mechatronic principles.
- **Milestone**: Deliverables package with working prototype.

## Required Materials and Tools
- **From Adafruit CPX Kit**: CPX board, USB cable, wires/jumpers, onboard sensors/NeoPixels.
- **New Components**:
  - Micro DC motor (e.g., N20 geared for torque).
  - LiPo battery (3.7V 500mAh, JST connector).
  - Wheels/rollers (3D-printed or with rubber O-rings).
  - Optional: HC-05 Bluetooth module, limit switches.
- **School-Supplied**: Tensioned steel cable, 3D printer, filament.
- **Tools**: Soldering iron (if available), multimeter, Mu Editor (free for CircuitPython).

## Potential Challenges and Mitigations
- **CPX Current Limits**: Use a motor driver (e.g., DRV8833) if motor current exceeds CPX capacity.
- **Cable Tension Variability**: Calibrate motor speed using accelerometer feedback.
- **3D Printing Issues**: Design chassis with tolerances for CPX; test-fit early.

This plan maximizes the CPX kit and school resources for a streamlined, Industry 4.0-aligned smart actuator.

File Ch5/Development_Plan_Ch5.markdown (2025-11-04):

# Development Plan for Conceptual Color Bead Sorting System

This development plan outlines a two-phase approach—Research and Design—for conceptualizing a color-based bead sorting system for your sensors and actuators class. The system focuses on separating yellow and blue beads using a hardware-driven, non-programmed approach, emphasizing sensor-actuator synergy without reliance on a controls narrative. Specific components are not required, so the plan prioritizes general principles and conceptual design informed by real-world examples.

## 1. Research Phase
Study real-world examples of color sorting machines to understand their operational principles, focusing on non-programmed, physics-driven mechanisms for sorting small objects like beads. The goal is to identify common design patterns and adapt them for a conceptual solution.

- **Study Objectives**:
  - Investigate how optical sensors detect color differences in real-world applications, such as distinguishing hues based on light reflectance or absorption properties.
  - Explore mechanical diversion methods (e.g., flaps, air jets, or gravity-driven paths) that respond directly to sensor signals without sequential programming.
  - Analyze system designs that leverage inherent material properties and environmental dynamics for sorting, avoiding complex control logic.
- **Sources to Explore**:
  - Industrial color sorters (e.g., used in agriculture for sorting grains or seeds) that employ optical sensors and pneumatic actuators for high-speed sorting. These often use simple thresholding circuits for real-time diversion.
  - Educational DIY projects, such as hobbyist sorting machines, which demonstrate gravity-fed chutes or conveyor systems paired with optical detection for small objects.
  - Technical literature on sensor-actuator integration in mechatronics, focusing on analog signal processing for immediate mechanical response.
- **Methodology**:
  - Review online resources like engineering blogs, open-source project repositories, and academic articles to gather insights on sorting mechanisms.
  - Document findings in a research log, noting key principles (e.g., spectral differentiation for color, mechanical bistability for diversion) and their applicability to bead sorting.
  - Synthesize pros and cons of observed designs, such as the trade-off between speed and accuracy in passive sorting systems.
- **Expected Outcomes**:
  - A clear understanding of how real-world systems achieve color-based sorting through direct sensor-actuator coupling.
  - A list of general design strategies (e.g., single-file bead flow, threshold-based actuation) to inform the conceptual design.
- **Timeline**: 1-2 weeks, allowing time to compile a comprehensive research log for reference in the design phase.

## 2. Design Phase
Develop a conceptual framework for a bead sorting system that separates yellow and blue beads, focusing on emergent behavior from sensor-actuator interactions rather than specific components or programmed steps.

- **Conceptual Framework**:
  - **Feed Mechanism**: Envision a sloped channel or vibrating surface that aligns beads into a single-file stream using gravity or gentle mechanical agitation, ensuring consistent presentation to the sensing zone without timed controls.
  - **Color Detection**: Conceive an optical sensing zone where beads’ reflective properties (yellow’s warmer, longer wavelengths vs. blue’s cooler, shorter wavelengths) produce distinct electrical signals. The sensor, conceptually a light-responsive device, generates an analog output that varies with color intensity.
  - **Diversion Mechanism**: Design a mechanical diverter, such as a pivoting gate or air pulse, activated directly by the sensor’s signal crossing a predefined threshold. One color follows a default path (e.g., straight through), while the other triggers a physical shift to an alternate path, leveraging bead momentum for separation.
  - **Collection**: Plan for two receiving bins with sloped or cushioned surfaces to prevent bead bouncing, ensuring clean separation.
- **Design Principles**:
  - Emphasize passive or semi-passive operation, where the system’s behavior emerges from physical interactions (e.g., light reflection, mechanical inertia) rather than orchestrated steps.
  - Incorporate adaptability for bead variations (e.g., size or glossiness) through adjustable detection thresholds or flexible mechanical design.
  - Ensure robustness against environmental factors, like ambient light, by conceptualizing shielding or consistent illumination in the sensing zone.
- **Deliverables**:
  - A detailed written description of the conceptual system, outlining how sensor signals drive actuation without programmed logic.
  - Hand-drawn or CAD-generated sketches illustrating the system layout, including the feed path, sensing zone, diverter, and bins.
  - A rationale section explaining how the design draws from real-world examples and addresses class objectives (e.g., avoiding controls narratives).
- **Timeline**: 1-2 weeks, producing a cohesive conceptual design document suitable for class submission.

This two-phase plan ensures a thorough understanding of real-world color sorting principles and their application to a conceptual bead sorting system. Total estimated time: 2-4 weeks, adaptable to class deadlines.

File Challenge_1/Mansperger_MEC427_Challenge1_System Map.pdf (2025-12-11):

Introduction

The Liquid Level Sensor System is a mechatronics training platform designed to demonstrate the integration of sensors, controls, and user calibration in a process environment. Its primary function is to detect the liquid level in a container of water and provide visual feedback through onboard indicators.

Hardware Architecture

The system is built around the **Adafruit Circuit Playground Express (CPX)**, which serves as the central controller. The CPX utilizes its capacitive touch sensor at pin **A1**, connected via a wired alligator clip secured to the rim of the container, to detect changes in capacitance caused by the presence of liquid. This sensing method allows the system to identify when the liquid reaches a defined level.d level.

Power and Feedback

Power is supplied by a **3.7V battery**, ensuring portability and safe operation in laboratory settings. The CPX's **NeoPixel LEDs** provide real-time feedback and are also used during manual calibration. Calibration enables adjustment for environmental conditions (humidity, temperature, container material) and for different liquids with varying dielectric properties, ensuring reliable detection across multiple scenarios.enarios.

## System Integration

This system highlights the integration of hardware (CPX, sensors, battery), software (calibration routines, LED control), and process control concepts. It serves as a practical demonstration of how mechatronic systems combine sensing, computation, and actuation to achieve robust functionality in real-world applications.

### System Overview

### Sequential Function Chart

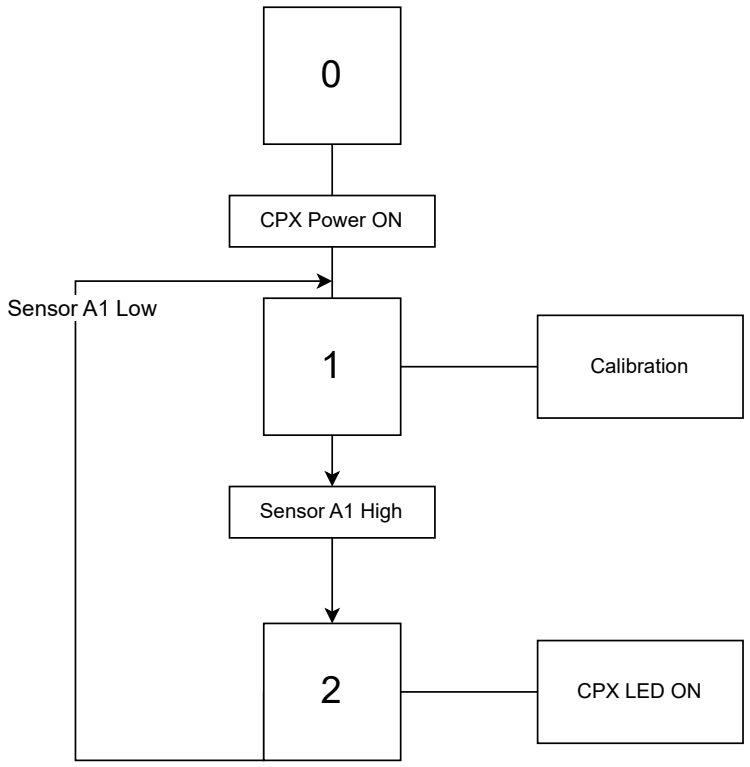
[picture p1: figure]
Sensor A1 Low; Sensor A1 High; CPX LED ON; CPX Power ON; Calibration
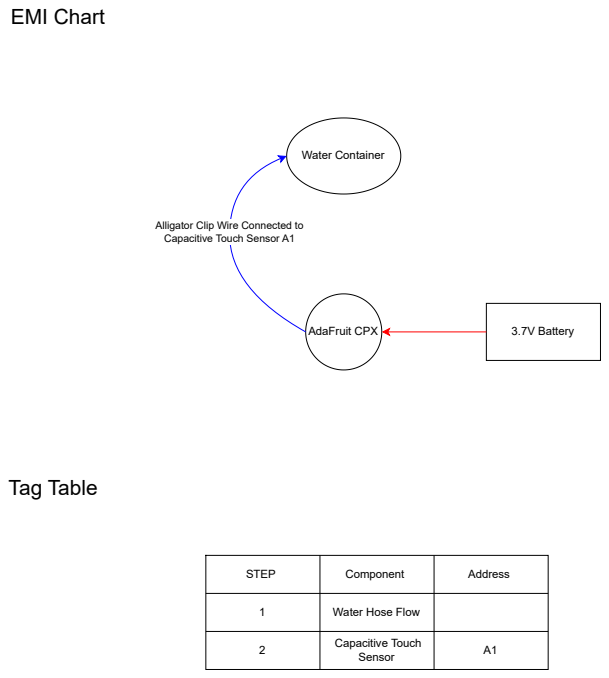
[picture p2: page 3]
Tag Table; AdaFruit CPX; Water Container; 3.7V Battery; EMI Chart

Alligator Clip Wire Connected to
Capacitive Touch Sensor A1

STEP | Component | Address

1 | Water Hose Flow

2 | Capacitive Touch Sensor | A1

import time
import board
import touchio
from adafruit_circuitplayground import cp

# Initialize the capacitive touch sensor on A1 touch_pad = touchio.TouchIn(board.A1)

# Settings for visualization and tuning

PIXEL_COUNT = 10
BAR_COLOR = (255, 160, 0) # amber for bar
THRESHOLD_COLOR = (255, 255, 255) # white marker (not flashing)

# Initialize NeoPixels

cp.pixels.brightness = 0.3
cp.pixels.fill((0, 0, 0))

# --- Auto-calibration on startup ---

# Show amber while calibrating the dry baseline cp.pixels[0] = (255, 140, 0) # amber

samples = []
for _ in range(40): # ~2 seconds at 0.05s/sample samples.append(touch_pad.raw_value) time.sleep(0.05)

# Use median for robustness to spikes

samples.sort()
dry_baseline = samples[len(samples) // 2]

# Load saved margin if present (plain text to avoid needing the json module) default_margin = 1000

threshold_margin = default_margin
try:

### Code

try:
with open("cal.txt", "r") as f: txt = f.read().strip()
threshold_margin = int(txt)
except Exception:
pass

# Threshold derived from baseline + margin detection_threshold = dry_baseline + threshold_margin

# End of calibration indicator: turn off pixel 0 (no white flash) cp.pixels[0] = (0, 0, 0)

# Debounce and UI state

wet_count = 0
dry_count = 0
is_wet = False

prev_btn_a = False
prev_btn_b = False
ab_hold_started_at = None
MARGIN_STEP_COUNTS = 100 # counts to change per button press BAR_SPAN_COUNTS = 2000 # map 0..BAR_SPAN across the 10 pixels

def clamp_int(value, lo, hi):
"""Clamp integer value to [lo, hi]."""
if value < lo:
return lo
if value > hi:
return hi
return value

def draw_bar_graph(raw_value, baseline, margin):
"""Draw bar of raw_value above baseline and white threshold marker.

raw_value: current capacitive reading
baseline: dry baseline captured on boot
margin: threshold offset above baseline

g
"""
# Compute bar level relative to baseline

delta = raw_value - baseline
delta = clamp_int(delta, 0, BAR_SPAN_COUNTS)
level = int((delta * PIXEL_COUNT) / BAR_SPAN_COUNTS) # 0..10

# Pixel index for threshold marker from margin position

m = clamp_int(margin, 0, BAR_SPAN_COUNTS)
t_idx = int((m * PIXEL_COUNT) / BAR_SPAN_COUNTS)
if t_idx >= PIXEL_COUNT:
t_idx = PIXEL_COUNT - 1

# Draw the bar with a solid white threshold marker at t_idx for i in range(PIXEL_COUNT):

if i == t_idx:
cp.pixels[i] = THRESHOLD_COLOR
elif i < level:
cp.pixels[i] = BAR_COLOR
else:
cp.pixels[i] = (0, 0, 0)

while True:
raw_value = touch_pad.raw_value

# Update detection with hysteresis if raw_value > detection_threshold: wet_count = min(wet_count + 1, 3) dry_count = 0

else:
dry_count = min(dry_count + 1, 3) wet_count = 0

new_is_wet = wet_count >= 2
if new_is_wet != is_wet:
is_wet = new_is_wet

# Show bar and threshold marker every loop draw_bar_graph(raw_value, dry_baseline, threshold_margin)

# Red LED indicates detection state (works without using NeoPixel colors) cp.red_led = is_wet

# Button edge detection for tuning

btn_a_pressed = cp.button_a
btn_b_pressed = cp.button_b

if btn_a_pressed and not prev_btn_a:
new_margin = threshold_margin - MARGIN_STEP_COUNTS threshold_margin = clamp_int(new_margin, 0, 8000) detection_threshold = dry_baseline + threshold_margin
# brief dim green blink on pixel 0

cp.pixels[0] = (0, 50, 0)
if btn_b_pressed and not prev_btn_b:
new_margin = threshold_margin + MARGIN_STEP_COUNTS threshold_margin = clamp_int(new_margin, 0, 8000) detection_threshold = dry_baseline + threshold_margin
# brief dim green blink on pixel 0

cp.pixels[0] = (0, 50, 0)

# Long press A+B to save margin (write plain integer to cal.txt) if btn_a_pressed and btn_b_pressed:

if ab_hold_started_at is None:
ab_hold_started_at = time.monotonic()
elif time.monotonic() - ab_hold_started_at > 1.0: try:
with open("cal.txt", "w") as f: f.write(str(int(threshold_margin)))
except Exception:
pass
# Flash green across ring to confirm save for _ in range(2):

for i in range(PIXEL_COUNT): cp.pixels[i] = (0, 100, 0)
time.sleep(0.15)
for i in range(PIXEL_COUNT): cp.pixels[i] = (0, 0, 0)
time.sleep(0.1)
ab hold started at = None

ab_hold_started_at None
else:
ab_hold_started_at = None

prev_btn_a = btn_a_pressed prev_btn_b = btn_b_pressed

time.sleep(0.06)

The Adafruit Circuit Playground Express (CPX) serves as the central controller for the Liquid Level Sensor System. It integrates sensing, computation, and user interface functions into a single compact platform, enabling reliable detection and calibration of liquid levels.
The CPX is powered by a 3.7V rechargeable battery, providing portable operation and safe voltage levels for laboratory use. Its capacitive touch sensor at pin A1 is configured as the primary input, connected via an alligator clip to the rim of the container. This sensor detects changes in capacitance caused by the presence of liquid, allowing the controller to determine when the water reaches the defined level.
The CPX also incorporates NeoPixel LEDs and onboard controls, which serve as both output indicators and calibration tools. The LEDs provide immediate visual feedback of sensor status, while the onboard buttons allow manual adjustment of sensitivity to account for environmental conditions (humidity, temperature, container material) and variations in liquid properties. This ensures accurate and adaptable operation across different scenarios.
Internally, the CPX executes a control program written in CircuitPython which manages sensor input, calibration routines, and output display. The program is modular, allowing easy modification for expanded functionality, such as multi-level detection or integration with external actuators.
By combining sensing, processing, and feedback in one device, the CPX demonstrates the principles of mechatronic control: integration of hardware, software, and user interaction to achieve robust system performance.

### Controller Overview

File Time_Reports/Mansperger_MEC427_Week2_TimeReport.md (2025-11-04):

# 🛠️ MEC 427 Advanced Sensors and Actuators Challenges 1-5

---

## 📅 Date & Time
- **Report Date:** `10-11-2025`
- **Time Block:** `10-06 – 10-10`
- **Time Spent This Session:** `5 hours`
- **Cumulative Time on Project:** `5 hours`

---

## 📂 Project Overview
- **Project Title:**  Challenge Development Plans
- **Project Objective:**  Create Initial Development Plans
- **Current Phase:** Sketching Phase

---

## 🔧 Task / Activity Details
- **Module / Subsystem:**  Development Plan
- **Specific Task or Activity:**  Documentation
- **Time Spent on This Task:** `2 hours`
- **% of Total Time:** `40%`
- **Resources Used:**  
  - **Hardware:**  
  - **Software:**  
  - **Tools:**  VScode, Markdown, Copilot, Grok
  - **Documentation:**  Development Plan (First Version)
  
###

- **Module / Subsystem:**  Hourly Report Template
- **Specific Task or Activity:**  Documentation
- **Time Spent on This Task:** `1 hours`
- **% of Total Time:** `20%`
- **Resources Used:**  
  - **Hardware:**  
  - **Software:**  
  - **Tools:**  VScode, Markdown, Copilot, Grok
  - **Documentation:**  Hourly Report Template
###
 **Module / Subsystem:**  Development Plan
- **Specific Task or Activity:**  Met with Carl for advice on development plan
- **Time Spent on This Task:** `1 hours`
- **% of Total Time:** `20%`
- **Resources Used:**  
  - **Hardware:**  
  - **Software:**  
  - **Tools:**  
  - **Documentation:** 

###
**Specific Task or Activity:**  Research on fluid sensors and systems
- **Time Spent on This Task:** `1 hours`
- **% of Total Time:** `20%`

---

## 📈 Progress Tracking
- **Task/Module Completion Status:** 
- **Project Completion Status:** 
- **Milestones Reached:**  Development plan started
- **Blockers or Issues:**  
- **Next Steps / Planned Actions:**  Refine and expand development plan once assignment details are provided.

---

## 📦 Results & Deliverables
- **What Was Achieved:** First Draft of development plan.  
- **Artifacts Created:** Development Plan v.1, Hourly Report Template
- **Validation / Testing Outcomes:**  
- **Changes Made to Design or Approach:** Using Markdown for documentation.  

---

## 👥 Team & Ownership
- **Persons Involved:**  
  - `Carl Wenngren – Advice`
- **Hand-offs or Dependencies:**  
  - -

---

## 📜 Narrative & Observations

- **Narrative Summary:**  
- Started out by seeking advice from Carl on creating my development plan and clarifying class structure. Also got some tips for project management and engineering. Found out that I may have deleted my OneDrive files during my virtual machine experimentation, So I decided to create new templates and documents in Markdown format as I find it cooperates with AI. Utilized AI tools like Copilot and Grok to help draft the development plan and report template. Spent some time researching fluid sensors and systems. Felt a bit inspired by the different applications available.
- **Technical Notes:**
- I will be using an external drive to back up my files going forward.  
- **Lessons Learned / Insights:** 
-  Learning a lot about different fluid sensors and applications.
- **Emotional/Workflow Reflections (optional):**
- Each project starts with a 'hump' to get over. Starting with the planning/sketching phase is a good foundation.

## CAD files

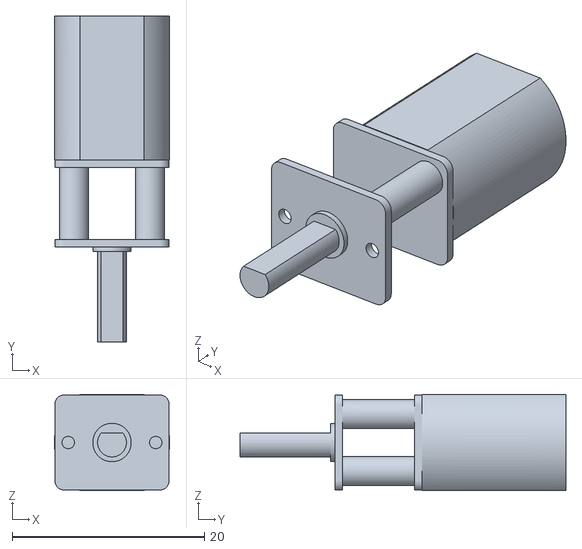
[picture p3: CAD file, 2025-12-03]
Ch4/N20_motor.stl
12.0 x 33.9 x 10.0

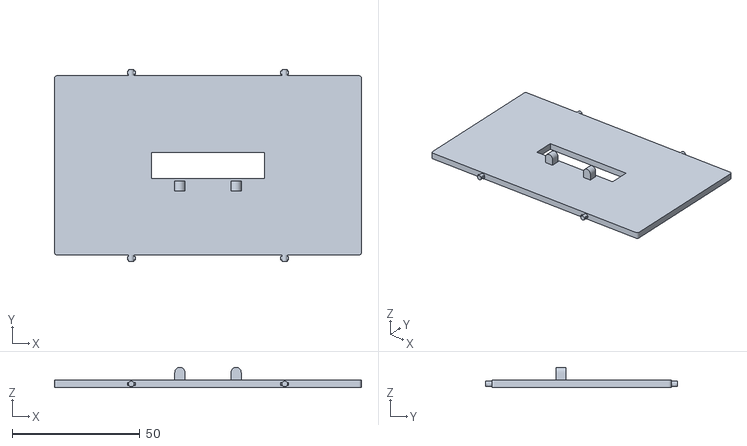
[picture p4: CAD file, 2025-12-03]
Ch4/Drive Plate.stl
120.0 x 75.0 x 8.00

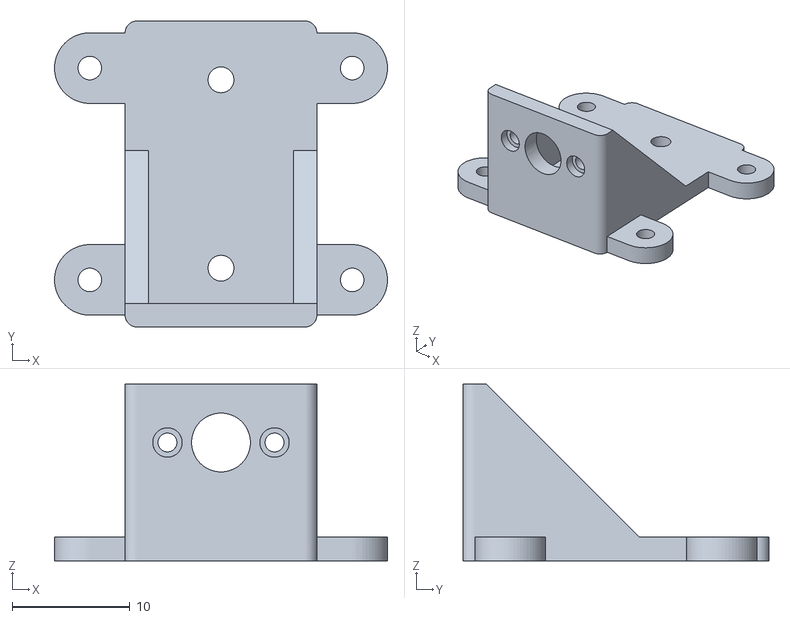
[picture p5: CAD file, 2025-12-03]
Ch4/N20_motor_mount_2.stl
28.3 x 26.0 x 15.0

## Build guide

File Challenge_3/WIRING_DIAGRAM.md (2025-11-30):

# Challenge 3: Wiring Diagram
## Smart Actuator - Voting Sensor + Servo Pinch Valve

```
┌─────────────────────────────────────────────────────────────────┐
│                  Circuit Playground Express (CPX)               │
│                                                                 │
│    ┌──────┐                                         ┌──────┐   │
│    │  A1  ├─────────────────────────────────────────┤Probe1│   │
│    └──────┘                                         └──────┘   │
│                                                                 │
│    ┌──────┐                                         ┌──────┐   │
│    │  A2  ├─────────────────────────────────────────┤Probe2│   │
│    └──────┘                                         └──────┘   │
│                                                                 │
│    ┌──────┐                                         ┌──────┐   │
│    │  A3  ├─────────────────────────────────────────┤Probe3│   │
│    └──────┘                                         └──────┘   │
│                                                                 │
│    ┌──────┐                                                    │
│    │  A6  ├─────────┐                                          │
│    └──────┘         │                                          │
│                     │                                          │
│    ┌──────┐         │      ┌─────────────────────────┐        │
│    │ GND  ├─────────┼──────┤        SG92R Servo      │        │
│    └──────┘         │      │  (External Power Reqd)  │        │
│                     │      └─────────────────────────┘        │
│    ┌──────┐         │                                          │
│    │ VOUT ├─────────┼─(NOT USED - See External Power Below)   │
│    └──────┘         │                                          │
│                     │                                          │
└─────────────────────┼──────────────────────────────────────────┘
                      │
                      │
            ┌─────────▼──────────┐
            │   SG92R SERVO      │
            │   CONNECTIONS:     │
            ├────────────────────┤
            │ BROWN  = GND       │◄──── Connect to CPX GND
            │ ORANGE = +5V       │◄──── Connect to External 5V Supply
            │ YELLOW = Signal    │◄──── Connect to CPX A6
            └────────────────────┘
```

---

## Component List

### Required Hardware

1. **Circuit Playground Express (CPX)**
   - Main microcontroller

2. **SG92R Servo Motor** (or compatible 5V micro servo)
   - Operating voltage: 4.8-6V
   - Operating current: ~250mA (under load)
   - Control signal: PWM (50Hz)

3. **Capacitive Touch Probes (3x)**
   - Bare copper wire, alligator clips, or conductive tape
   - Length: 4-6 inches recommended
   - Gauge: 22-24 AWG solid core wire works well

4. **External Power Supply for Servo**
   - **5V DC, 500mA+ recommended**
   - Options:
     - USB power bank (5V output)
     - 4x AA battery holder (4.8-6V)
     - Bench power supply (5V setting)
   - ⚠️ **DO NOT power servo from CPX VOUT** - insufficient current capacity

5. **Pinch Valve Mechanism** (your implementation)
   - Flexible tubing (silicone recommended)
   - Servo horn/arm attachment
   - Mounting bracket/frame

---

## Detailed Wiring Instructions

### Step 1: Capacitive Sensor Connections

**Probe 1 → A1**
- Strip 1/4" of wire insulation
- Insert into CPX pad A1 or use alligator clip
- Sensing tip: 1-2" exposed bare wire at far end
- Insulate all wire except sensing tip

**Probe 2 → A3**
- Same as Probe 1, connect to A3

**Probe 3 → A5**
- Same as Probe 1, connect to A5

**Probe Placement:**
```
Container/Tank View:
┌─────────────────┐
│                 │
│   ●  Probe 1    │  ← Spread probes apart
│      (A1)       │    Non-adjacent pads reduce
│                 │    capacitive cross-talk
│        ●  Probe 2   
│           (A3)  │
│                 │
│   ●  Probe 3    │
│      (A5)       │
│                 │
└─────────────────┘
```

---

### Step 2: Servo Motor Connections

**Servo Wire Colors (Your Servo):**
- **BROWN** = Ground (GND)
- **ORANGE** = Power (+5V)
- **YELLOW** = PWM Signal

**Connections:**

1. **BROWN (GND) → CPX GND**
   - Use any available GND pad on CPX
   - ⚠️ **CRITICAL**: Servo GND MUST share common ground with CPX

2. **YELLOW (Signal) → CPX A6**
   - This is the PWM control signal
   - CPX sends 50Hz pulses to control servo position
   - Duty cycle: 1.0ms (0°) to 1.5ms (90°)

3. **ORANGE (Power) → External 5V Supply (+)**
   - Connect to **positive terminal** of external power source
   - **DO NOT connect to CPX VOUT** (insufficient current)

4. **External Power GND → CPX GND**
   - Connect **negative terminal** of external power to CPX GND
   - Creates common ground reference (required for PWM signal)

---

### Step 3: External Power Setup

**Option A: USB Power Bank**
```
USB Power Bank (5V, 1A+)
    │
    ├─── USB cable ───> Cut cable and expose wires
    │                   RED (+5V) ──> Servo ORANGE
    │                   BLACK (GND) ──> Servo BROWN + CPX GND
```

**Option B: Battery Pack**
```
4x AA Batteries (6V total)
    │
    ├─── (+) Terminal ──> Servo ORANGE
    └─── (-) Terminal ──> Servo BROWN + CPX GND
```

**Option C: Bench Power Supply**
```
Bench PSU (set to 5.0V, limit 500mA)
    │
    ├─── (+) Red Terminal ──> Servo ORANGE
    └─── (-) Black Terminal ──> Servo BROWN + CPX GND
```

---

## Complete Wiring Schematic

```
                    ┌─────────────────────┐
                    │   External 5V PSU   │
                    │   (500mA minimum)   │
                    └──────┬──────┬───────┘
                           │      │
                          +5V    GND
                           │      │
        ┌──────────────────┼──────┼─────────────────────┐
        │                  │      │                     │
        │  CPX             │      │                     │
        │                  │      │                     │
        │  A1 ●────────────┼──────┼─────► Probe 1      │
        │                  │      │                     │
        │  A2 ●────────────┼──────┼─────► Probe 2      │
        │                  │      │                     │
        │  A3 ●────────────┼──────┼─────► Probe 3      │
        │                  │      │                     │
        │  A6 ●────────────┼──────┼───┐                │
        │                  │      │   │                │
        │ GND ●────────────┼──────┴───┼────┐           │
        │                  │          │    │           │
        └──────────────────┼──────────┼────┼───────────┘
                           │          │    │
                           │          │    │
                     ┌─────▼──────────▼────▼─────┐
                     │      SG92R SERVO          │
                     │                           │
                     │  ORANGE = +5V (External)  │
                     │  YELLOW = Signal (A6)     │
                     │  BROWN  = GND (Common)    │
                     └───────────────────────────┘
```

---

## Safety & Best Practices

### ⚠️ **CRITICAL WARNINGS**

1. **DO NOT power servo from CPX VOUT**
   - CPX VOUT max current: ~200mA
   - Servo stall current: 250-500mA
   - **Risk**: Brownout, CPX reset, USB port damage

2. **ALWAYS connect common ground**
   - External power GND MUST connect to CPX GND
   - Without common ground, PWM signal will not work correctly

3. **Use appropriate wire gauge**
   - Servo power wires: 22 AWG or thicker
   - Signal wires: 24-26 AWG acceptable

4. **Secure all connections**
   - Loose wires can cause intermittent operation
   - Use solder or secure screw terminals for power connections

### ✅ **Best Practices**

1. **Test servo separately first**
   - Use `Servo_Test.py` to verify servo operation
   - Confirm full range of motion (0° to 90°)

2. **Calibrate probes with valve OPEN**
   - Run calibration with no water present
   - Ensures accurate baseline readings

3. **Mount CPX on non-conductive surface**
   - Plastic mounting reduces ground coupling noise
   - Keeps sensor readings stable

4. **Keep servo wires short**
   - Minimize signal wire length to A6
   - Reduces electrical noise and voltage drop

5. **Add optional capacitor**
   - 100-470µF across servo power (+/-)
   - Smooths power spikes during servo motion
   - Not required but recommended for stability

---

## Pinch Valve Mechanical Setup

### Suggested Mounting

```
Side View:
                  Servo Motor
                  ┌────────┐
                  │ SG92R  │
                  └────┬───┘
                       │ Servo Horn (arm)
                       ▼
                  ┌────────┐
                  │ Pinch  │  ← Presses down on tube
                  │ Plate  │
                  └────┬───┘
                       │
    ═══════════════════●═══════════════════  ← Flexible tubing
                     Pinch point
                       ▲
                  ┌────┴───┐
                  │ Base   │
                  │ Plate  │
                  └────────┘
```

**Components:**
- **Servo Horn**: Attached to servo shaft
- **Pinch Plate**: Flat surface (plastic, metal) to compress tube
- **Flexible Tubing**: Silicone (4-6mm OD recommended)
- **Base Plate**: Provides back-pressure for pinching

**Servo Positions:**
- **0° (SERVO_OPEN)**: Horn up, tube unrestricted
- **90° (SERVO_CLOSED)**: Horn down, tube fully pinched

---

## Testing Procedure

### 1. Hardware Check (No Code)
- [ ] All 3 probes connected to A1, A2, A3
- [ ] Servo YELLOW connected to A6
- [ ] Servo BROWN connected to CPX GND
- [ ] Servo ORANGE connected to external 5V supply
- [ ] External power GND connected to CPX GND
- [ ] CPX powered via USB

### 2. Servo Test
```bash
# Deploy Servo_Test.py to CPX
# Observe servo moving through positions
# Verify full range of motion
```

### 3. Sensor Test (Dry)
```bash
# Deploy code.py to CPX
# Check serial output:
# - Baselines should be ~1500-1700 per probe
# - All probes show "wet: False"
# - Majority: False
# - Red LED: OFF
```

### 4. Sensor Test (Wet)
```bash
# Touch 2 probes with wet finger or water
# Check serial output:
# - 2 probes show "wet: True"
# - Majority: True
# - Red LED: ON
# - Servo closes valve
```

### 5. Full System Test
```bash
# With valve mechanism installed:
# 1. Power on (valve should open)
# 2. Touch 2+ probes to water
# 3. Valve should close (verify tube pinched)
# 4. Remove probes from water
# 5. Valve should open (verify tube unpinched)
```

---

## Troubleshooting

### Servo doesn't move
- ✓ Check external power supply is ON and 5V
- ✓ Verify YELLOW wire connected to A6
- ✓ Verify ORANGE wire connected to external +5V
- ✓ Verify BROWN wire connected to CPX GND
- ✓ Confirm common ground (GND) between CPX and external power
- ✓ Test with `Servo_Test.py`

### Servo jitters/buzzes
- ✓ Add 100µF capacitor across servo power
- ✓ Check power supply current capacity (500mA+)
- ✓ Reduce servo load (pinch valve may be too tight)

### Sensors don't detect water
- ✓ Verify probes connected to A1, A2, A3
- ✓ Check baselines in serial output
- ✓ Adjust threshold margin with Button B
- ✓ Hold Button A for 2s to recalibrate

### Red LED on but no water detected
- ✓ Threshold margin too low (increase with Button B)
- ✓ Recalibrate baselines (hold Button A)
- ✓ Check for electrical noise (move CPX to plastic surface)

### Valve doesn't fully close/open
- ✓ Adjust `SERVO_OPEN` and `SERVO_CLOSED` values in code
- ✓ Check servo horn alignment
- ✓ Verify tube flexibility (silicone works best)

---

## Code Constants Reference

```python
# Servo PWM duty cycles (adjust if needed)
SERVO_OPEN = 3277      # 1.0ms pulse = 0° (valve open)
SERVO_CLOSED = 4915    # 1.5ms pulse = 90° (valve closed)

# Sensor thresholds
threshold_margin = 1000  # Default sensitivity (adjustable with A/B buttons)

# Detection voting
# Requires 2 out of 3 probes to detect water
majority_wet = (probe_wet.count(True) >= 2)
```

---

## Visual Feedback (NeoPixels)

**LED Pattern:**
- **Pixels 0-2**: Probe 1 (A1) status
  - Cyan = wet detected
  - Dim green = dry
- **Pixels 3-5**: Probe 2 (A3) status
- **Pixels 6-8**: Probe 3 (A5) status
- **Pixel 9**: Majority vote result
  - Red = majority wet (valve closed)
  - Green = majority dry (valve open)

**Red Status LED:**
- ON = Water detected (majority), valve closed
- OFF = No water (majority), valve open

---

*Wiring diagram created for MEC 427 Challenge 3*  
*Date: November 30, 2025*

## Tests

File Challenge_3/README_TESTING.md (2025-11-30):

# Challenge 3 Unit Testing

## Overview
Unit tests for the Smart Actuator voting logic, hysteresis, threshold calculations, and auto-tracking features.

## Running Tests

### Run all tests:
```bash
python test_code.py
```

### Run with verbose output:
```bash
python test_code.py -v
```

### Run specific test class:
```bash
python -m unittest test_code.TestVotingLogic
```

### Run specific test method:
```bash
python -m unittest test_code.TestVotingLogic.test_majority_vote_two_true
```

## Test Coverage

### TestVotingLogic
Tests the majority voting mechanism (2 out of 3 probes):
- ✓ Two probes wet triggers majority
- ✓ Three probes wet triggers majority
- ✓ One probe wet does not trigger majority
- ✓ Zero probes wet does not trigger majority

### TestHysteresisLogic
Tests the hysteresis counter system:
- ✓ Wet count increments when out of threshold
- ✓ Dry count increments when within threshold
- ✓ Counts don't exceed maximum (3)
- ✓ Probe state changes at count >= 2

### TestThresholdCalculation
Tests threshold and margin calculations:
- ✓ High/low thresholds calculated from baselines
- ✓ Margin decrease with button A
- ✓ Margin increase with button B
- ✓ Margin limits (0 minimum, 8000 maximum)

### TestAutoTracking
Tests baseline drift compensation:
- ✓ Baseline adjusts upward for higher readings
- ✓ Baseline adjusts downward for lower readings
- ✓ No adjustment for small differences
- ✓ Tracking only when all probes dry
- ✓ Tracking disabled when wet

### TestBaselineCapture
Tests calibration logic:
- ✓ Median value selection from readings
- ✓ Readings properly sorted

### TestServoControl
Tests servo state management:
- ✓ PWM values are correct and distinct
- ✓ State change detection (dry→wet, wet→dry, no change)

## Expected Output

```
..................................
----------------------------------------------------------------------
Ran 34 tests in 0.001s

OK
```

## Adding New Tests

1. Create a new test class inheriting from `unittest.TestCase`
2. Add test methods starting with `test_`
3. Use assertions: `assertEqual`, `assertTrue`, `assertFalse`, etc.
4. Run tests to verify

Example:
```python
class TestNewFeature(unittest.TestCase):
    def test_feature_behavior(self):
        result = my_function(input_value)
        self.assertEqual(result, expected_value)
```

## Integration Testing

Note: These unit tests cover logic only. For hardware integration testing:
1. Deploy code to CIRCUITPY
2. Manually test with actual probes and servo
3. Verify LED feedback matches probe states
4. Test button sensitivity adjustments

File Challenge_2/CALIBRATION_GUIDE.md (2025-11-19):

# Challenge 2: Voting Capacitive Water Sensor - Calibration Guide

## System Overview

This capacitive water sensor uses a **3-sensor voting array** with majority logic detection. The system requires at least 2 out of 3 sensors to detect water before triggering, providing fault tolerance and preventing false positives.

### Hardware Configuration
- **Sensors**: 3 non-adjacent capacitive touch pads (A1, A3, A5)
- **Sensor Spacing**: Non-adjacent pins to reduce cross-talk and electrical coupling
- **Mounting**: CPX on plastic mount to eliminate ground coupling issues
- **Probes**: Direct wire connection (no alligator clips) for stable readings

### Detection Logic
- **Majority Voting**: Requires 2 out of 3 sensors to agree
- **Bidirectional Detection**: Triggers on large delta changes (positive OR negative)
- **Smoothing**: EMA filter (α=0.3) for noise reduction
- **Hysteresis**: 2-sample confirmation to prevent flickering

---

## Calibration Procedure

### Step 1: Physical Setup
1. **Mount the CPX** on a non-conductive (plastic) surface
2. **Attach probes** to pads A1, A3, and A5:
   - Use direct wire connections (avoid alligator clips if possible)
   - Insulate all wiring except the sensing tips
   - Space probes physically in the container to reduce coupling
3. **Ensure all probes are DRY** before powering on

### Step 2: Auto-Calibration on Boot
1. **Remove all probes from water** (critical!)
2. **Connect CPX to power** or press the reset button
3. **Observe pixel 0 turn amber** - calibration in progress
4. **Wait 6 seconds** for calibration to complete (120 samples per sensor)
5. **Pixel 0 turns off** - calibration complete, dry baselines captured

**Important**: If probes are wet during calibration, the system will not work correctly. Always recalibrate with dry probes.

### Step 3: Verify Dry Baseline
Open serial monitor and check the output with all probes dry:
```
r: [1709, 1682, 1551] d: [-6, -1, -16] ... wet: [False, False, False] maj: False
```

- `r:` Raw sensor values (should be stable)
- `d:` Delta from baseline (should be near 0, typically ±20 counts)
- `wet:` Per-sensor flags (should all be False)
- `maj:` Majority decision (should be False)

### Step 4: Test Single Probe Detection
1. **Immerse only one probe** in water
2. **Check serial output**:
   ```
   wet: [True, False, False] maj: False
   ```
   - One sensor shows `True`
   - Majority (`maj`) remains `False` (1 out of 3 is not enough)

### Step 5: Test Majority Voting
1. **Immerse two probes** in water
2. **Check serial output**:
   ```
   wet: [True, True, False] maj: True
   ```
   - Two sensors show `True`
   - Majority (`maj`) is now `True` (2 out of 3)
   - **Red LED turns on**

### Step 6: Test All-Probes Detection
1. **Immerse all three probes** in water
2. **Check serial output**:
   ```
   r: [16, 22, 16] d: [-1705, -1665, -1543] ... wet: [True, True, True] maj: True
   ```
   - All sensors show `True`
   - Deltas are **negative** (common-mode shift in conductive water)
   - Detection still works (bidirectional logic handles this)
   - **Amber bar graph shows magnitude** of change

### Step 7: Manual Threshold Adjustment (Optional)
If detection is too sensitive or not sensitive enough:

- **Button A**: Decrease margin (more sensitive, lower threshold)
- **Button B**: Increase margin (less sensitive, higher threshold)
- **Hold A+B for 1 second**: Save current margin to `cal.txt` (green flash confirms)

Current default margin: **1000 counts**

---

## Understanding Serial Debug Output

Example output:
```
r: [1709, 1682, 1551] d: [-6, -1, -16] thr_lo: [722, 673, 577] thr_hi: [2722, 2673, 2577] wet: [False, False, False] maj: False margin: 1000
```

### Field Definitions
- **r:** Raw capacitance readings per sensor [A1, A3, A5]
- **d:** Delta from baseline (raw - baseline) per sensor
- **thr_lo:** Lower threshold (baseline - margin) per sensor
- **thr_hi:** Upper threshold (baseline + margin) per sensor
- **wet:** Per-sensor detection flags (True if |delta| > margin)
- **maj:** Majority voting result (True if ≥2 sensors detect water)
- **margin:** Current threshold margin (adjustable with A/B buttons)

---

## Expected Behavior Summary

### Dry Condition
- Deltas: ±20 counts or less
- Wet flags: All False
- Majority: False
- Red LED: Off
- Bar graph: Minimal or no amber bar

### One Probe Wet
- Deltas: One large (±1000-2000), others small
- Wet flags: One True, two False
- Majority: **False** (fault tolerance - single sensor ignored)
- Red LED: Off

### Two Probes Wet
- Deltas: Two large, one small
- Wet flags: Two True, one False
- Majority: **True** (2/3 consensus reached)
- Red LED: On
- Bar graph: Large amber bar

### Three Probes Wet
- Deltas: All large (may be negative due to common-mode shift)
- Wet flags: All True
- Majority: **True**
- Red LED: On
- Bar graph: Large amber bar

---

## Troubleshooting

### Problem: Erratic delta readings
**Causes:**
- Alligator clips with poor contact
- CPX on metal/conductive surface
- Probes too close together

**Solutions:**
- Use direct wire connections (solder + heat shrink)
- Mount CPX on plastic
- Space probes farther apart in container

### Problem: Negative deltas when all probes are wet
**Status:** Normal behavior
- Conductive water creates common-mode voltage shift
- Bidirectional detection handles this automatically
- System triggers correctly on absolute delta magnitude

### Problem: False triggers when dry
**Cause:** Threshold margin too low

**Solution:**
- Press Button B to increase margin
- Hold A+B to save new setting

### Problem: No detection when wet
**Causes:**
- Calibrated while probes were wet
- Threshold margin too high
- Poor probe contact with water

**Solutions:**
1. Reset CPX with dry probes to recalibrate
2. Press Button A to decrease margin
3. Check probe insulation - ensure sensing tips are exposed

### Problem: Bar graph disappears when wet
**Status:** Fixed in current version
- Display now uses absolute delta magnitude
- Works correctly with both positive and negative deltas

---

## Technical Details

### Noise Filtering
- **EMA Smoothing**: α = 0.3 (70% previous + 30% new reading)
- **Calibration**: 120-sample median per sensor (6 seconds)
- **Hysteresis**: 2-sample confirmation (wet_count ≥ 2)

### Signal Characteristics
- **Dry baseline**: ~1500-1700 counts (varies per sensor)
- **Single wet delta**: +1000 to +2000 counts (positive)
- **Multi wet delta**: -1500 to -1700 counts (negative, common-mode shift)
- **Default margin**: 1000 counts

### Physical Considerations
- **Electrode area**: Larger = more sensitivity
- **Wire length**: Shorter = less noise
- **Probe spacing**: Farther = less coupling
- **Water conductivity**: Higher = stronger common-mode effect

---

## Recommended Workflow

1. **Setup**: Mount CPX on plastic, attach dry probes
2. **Calibrate**: Power on with dry probes, wait 6 seconds
3. **Verify**: Check serial - deltas near 0 when dry
4. **Test voting**: 1 probe (maj: False), 2 probes (maj: True), 3 probes (maj: True)
5. **Tune** (if needed): Adjust margin with A/B buttons
6. **Save**: Hold A+B to save threshold to persistent storage

---

## Version History

**Current Version**: V3 Final
- Multi-sensor voting array (A1, A3, A5)
- Majority logic (2 out of 3)
- Bidirectional delta detection
- Absolute magnitude bar graph display
- EMA smoothing (α=0.3)
- Enhanced calibration (120 samples)
- Serial debug output

---

## Files
- **code.py**: Main sensor code (deployed to CPX)
- **cal.txt**: Saved threshold margin (created when A+B held)
- **CALIBRATION_GUIDE.md**: This document

---

*Last Updated: November 11, 2025*

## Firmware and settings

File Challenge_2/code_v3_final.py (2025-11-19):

"""Version 3: Final - with EMA smoothing and debug output"""

import time
import board
import touchio
from adafruit_circuitplayground import cp

# Initialize three non-adjacent touch pads
touch_pads = [
    touchio.TouchIn(board.A1),
    touchio.TouchIn(board.A3),
    touchio.TouchIn(board.A5),
]

# Settings
PIXEL_COUNT = 10
BAR_COLOR = (255, 160, 0)
THRESHOLD_COLOR = (255, 255, 255)

cp.pixels.brightness = 0.3
cp.pixels.fill((0, 0, 0))

# Per-pad calibration with more samples
cp.pixels[0] = (255, 140, 0)
sample_lists = [[], [], []]
CAL_SAMPLES = 120
for _ in range(CAL_SAMPLES):
    for i in range(3):
        sample_lists[i].append(touch_pads[i].raw_value)
    time.sleep(0.05)

# Calculate per-pad baselines
dry_baselines = []
for i in range(3):
    sample_lists[i].sort()
    dry_baselines.append(sample_lists[i][len(sample_lists[i]) // 2])

# Thresholds
default_margin = 1000
threshold_margin = default_margin
detection_thresholds = []
for b in dry_baselines:
    detection_thresholds.append(b + threshold_margin)

cp.pixels[0] = (0, 0, 0)

# State
wet_count = 0
dry_count = 0
is_wet = False

prev_btn_a = False
prev_btn_b = False

BAR_SPAN_COUNTS = 2000
MARGIN_STEP_COUNTS = 100

# Smoothing
SMOOTHING_ALPHA = 0.25
smoothed_values = [None, None, None]

# Debug
DEBUG = True


def clamp_int(value, lo, hi):
    if value < lo:
        return lo
    if value > hi:
        return hi
    return value


def draw_bar_graph(raw_value, baseline, margin):
    delta = raw_value - baseline
    delta = clamp_int(delta, 0, BAR_SPAN_COUNTS)
    level = int((delta * PIXEL_COUNT) / BAR_SPAN_COUNTS)
    
    m = clamp_int(margin, 0, BAR_SPAN_COUNTS)
    t_idx = int((m * PIXEL_COUNT) / BAR_SPAN_COUNTS)
    if t_idx >= PIXEL_COUNT:
        t_idx = PIXEL_COUNT - 1
    
    for i in range(PIXEL_COUNT):
        if i == t_idx:
            cp.pixels[i] = THRESHOLD_COLOR
        elif i < level:
            cp.pixels[i] = BAR_COLOR
        else:
            cp.pixels[i] = (0, 0, 0)


while True:
    # Read all pads
    raw_values = []
    for i in range(3):
        raw_values.append(touch_pads[i].raw_value)
    
    # Apply EMA smoothing
    for i in range(3):
        if smoothed_values[i] is None:
            smoothed_values[i] = raw_values[i]
        else:
            smoothed_values[i] = int(smoothed_values[i] * (1 - SMOOTHING_ALPHA) + raw_values[i] * SMOOTHING_ALPHA)
    
    # Use smoothed values
    for i in range(3):
        raw_values[i] = smoothed_values[i]
    
    # Use max for display
    raw_value = raw_values[0]
    if raw_values[1] > raw_value:
        raw_value = raw_values[1]
    if raw_values[2] > raw_value:
        raw_value = raw_values[2]
    
    # Check if any pad triggered
    any_triggered = False
    for i in range(3):
        if raw_values[i] > detection_thresholds[i]:
            any_triggered = True
            break
    
    if any_triggered:
        wet_count = min(wet_count + 1, 3)
        dry_count = 0
    else:
        dry_count = min(dry_count + 1, 3)
        wet_count = 0
    
    new_is_wet = wet_count >= 2
    if new_is_wet != is_wet:
        is_wet = new_is_wet
    
    # Debug output
    if DEBUG:
        deltas = []
        thr_lo = []
        thr_hi = []
        wet_per_pad = []
        for i in range(3):
            deltas.append(raw_values[i] - dry_baselines[i])
            thr_lo.append(dry_baselines[i] - threshold_margin)
            thr_hi.append(dry_baselines[i] + threshold_margin)
            wet_per_pad.append(raw_values[i] > detection_thresholds[i])
        
        print("r:", raw_values, "d:", deltas, "thr_lo:", thr_lo, "thr_hi:", thr_hi, "wet:", wet_per_pad, "maj:", is_wet, "margin:", threshold_margin)
    
    # Use min baseline for display
    display_baseline = dry_baselines[0]
    if dry_baselines[1] < display_baseline:
        display_baseline = dry_baselines[1]
    if dry_baselines[2] < display_baseline:
        display_baseline = dry_baselines[2]
    
    draw_bar_graph(raw_value, display_baseline, threshold_margin)
    cp.red_led = is_wet
    
    # Button controls
    btn_a_pressed = cp.button_a
    btn_b_pressed = cp.button_b
    
    if btn_a_pressed and not prev_btn_a:
        new_margin = threshold_margin - MARGIN_STEP_COUNTS
        threshold_margin = clamp_int(new_margin, 0, 8000)
        for i in range(3):
            detection_thresholds[i] = dry_baselines[i] + threshold_margin
        cp.pixels[0] = (0, 50, 0)
    
    if btn_b_pressed and not prev_btn_b:
        new_margin = threshold_margin + MARGIN_STEP_COUNTS
        threshold_margin = clamp_int(new_margin, 0, 8000)
        for i in range(3):
            detection_thresholds[i] = dry_baselines[i] + threshold_margin
        cp.pixels[0] = (0, 50, 0)
    
    prev_btn_a = btn_a_pressed
    prev_btn_b = btn_b_pressed
    
    time.sleep(0.06)

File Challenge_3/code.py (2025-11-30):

"""Smart actuator: voting sensor + servo-controlled pinch valve.

3-probe voting (A1, A3, A5) triggers SG92R servo (A6) to close pinch valve.
Uses minimal PWM approach for power stability with external servo power.
Non-adjacent pads reduce capacitive cross-talk between sensors.
"""

import time

import board
import pwmio
import touchio
from adafruit_circuitplayground import cp

# Initialize sensors on non-adjacent pads to reduce cross-talk
touch_pads = [
    touchio.TouchIn(board.A1),
    touchio.TouchIn(board.A3),
    touchio.TouchIn(board.A5),
]

# Servo PWM values (50Hz)
SERVO_OPEN = 3277      # 1.0ms pulse = 0°
SERVO_CLOSED = 4915    # 1.5ms pulse = 90°

# Keep PWM active for servo control
servo_pwm = pwmio.PWMOut(board.A6, frequency=50)


def move_servo(duty_cycle):
    """Move servo and hold position with continuous PWM."""
    servo_pwm.duty_cycle = duty_cycle
    time.sleep(0.5)  # Give servo time to reach position


# Initialize servo to open position
move_servo(SERVO_OPEN)
print("Servo initialized to OPEN position")
print("Baselines will be captured in 2 seconds...")

# Simplified settings
PIXEL_COUNT = 10
cp.pixels.brightness = 0.2
cp.pixels.fill((0, 0, 0))

# Auto-calibration (simplified - fewer samples)


def capture_baseline(pad):
    readings = []
    for _ in range(20):  # reduced from 40
        readings.append(pad.raw_value)
        time.sleep(0.05)
    readings.sort()
    return readings[10]


cp.pixels[0] = (255, 140, 0)
dry_baselines = [capture_baseline(p) for p in touch_pads]
cp.pixels[0] = (0, 0, 0)
print(
    f"Baselines: A1={dry_baselines[0]}, "
    f"A3={dry_baselines[1]}, A5={dry_baselines[2]}")

# Load margin
threshold_margin = 1000
try:
    with open("cal.txt", "r") as f:
        threshold_margin = int(f.read().strip())
except (OSError, ValueError):
    pass

thr_lo = [b - threshold_margin for b in dry_baselines]
thr_hi = [b + threshold_margin for b in dry_baselines]

print(f"Threshold margin: {threshold_margin}")
print("=== System Ready ===")
print("Touch 2+ probes to close valve (red LED on)")
print("Remove probes to open valve (red LED off)")
print("Button A: decrease sensitivity | Button B: increase sensitivity")
print()

# Servo already initialized to OPEN and deinitialized above

# State
wet_counts = [0, 0, 0]
dry_counts = [0, 0, 0]
probe_wet = [False, False, False]
majority_wet = False
prev_majority_wet = False

prev_btn_a = False
prev_btn_b = False
MARGIN_STEP = 100

# Auto-tracking state
tracking_enabled = True
TRACKING_RATE = 0.02  # 2% adjustment per update
TRACKING_INTERVAL = 50  # Update every 50 loops (~5 sec)
loop_count = 0


while True:
    raw_values = [p.raw_value for p in touch_pads]

    # Per-probe hysteresis
    for i in range(3):
        if (raw_values[i] > thr_hi[i]) or (raw_values[i] < thr_lo[i]):
            wet_counts[i] = min(wet_counts[i] + 1, 3)
            dry_counts[i] = 0
        else:
            dry_counts[i] = min(dry_counts[i] + 1, 3)
            wet_counts[i] = 0
        probe_wet[i] = wet_counts[i] >= 2

    # Majority vote
    majority_wet = (probe_wet.count(True) >= 2)

    # Auto-tracking: slowly adjust baselines when all probes agree (dry)
    if tracking_enabled and not majority_wet:
        loop_count += 1
        if loop_count >= TRACKING_INTERVAL:
            loop_count = 0
            if probe_wet.count(False) == 3:  # All dry
                for i in range(3):
                    diff = raw_values[i] - dry_baselines[i]
                    adjustment = int(diff * TRACKING_RATE)
                    if abs(adjustment) > 0:
                        dry_baselines[i] += adjustment
                        thr_lo[i] = dry_baselines[i] - threshold_margin
                        thr_hi[i] = dry_baselines[i] + threshold_margin

    # Control servo (only when state changes - minimal PWM pulses)
    if majority_wet and not prev_majority_wet:
        print("MAJORITY WET -> Closing valve")
        move_servo(SERVO_CLOSED)
        cp.red_led = True
    elif not majority_wet and prev_majority_wet:
        print("MAJORITY DRY -> Opening valve")
        move_servo(SERVO_OPEN)
        cp.red_led = False
    prev_majority_wet = majority_wet

    # Simple visualization - light pixel count based on wet probes
    wet_count_total = probe_wet.count(True)
    for i in range(PIXEL_COUNT):
        if i < wet_count_total * 3:
            cp.pixels[i] = (100, 50, 0)
        else:
            cp.pixels[i] = (0, 0, 0)

    # Detailed LED bar graph - show individual probe status
    # Probes: A1=pixels 0-2, A2=pixels 3-5, A3=pixels 6-8, pixel 9=majority
    for i in range(3):
        color = (0, 100, 100) if probe_wet[i] else (0, 20, 0)
        for j in range(3):
            cp.pixels[i * 3 + j] = color
    # Pixel 9 shows majority vote status
    cp.pixels[9] = (255, 0, 0) if majority_wet else (0, 50, 0)

    # Button tuning
    btn_a = cp.button_a
    btn_b = cp.button_b

    if btn_a and not prev_btn_a:
        threshold_margin = max(0, threshold_margin - MARGIN_STEP)
        thr_lo = [b - threshold_margin for b in dry_baselines]
        thr_hi = [b + threshold_margin for b in dry_baselines]
        print(f"Margin decreased to {threshold_margin}")
    if btn_b and not prev_btn_b:
        threshold_margin = min(8000, threshold_margin + MARGIN_STEP)
        thr_lo = [b - threshold_margin for b in dry_baselines]
        thr_hi = [b + threshold_margin for b in dry_baselines]
        print(f"Margin increased to {threshold_margin}")

    prev_btn_a = btn_a
    prev_btn_b = btn_b

    time.sleep(0.1)

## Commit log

2025-11-04 Complete Challenge 1: calibrated water sensor with threshold 2500, add README and Pylance stubs
2025-11-11 Challenge 2: Implement 3-sensor voting array with majority logic
    - Added multi-sensor support (A1, A3, A5) to reduce cross-talk
    - Implemented majority voting logic (2 out of 3 sensors required)
    - Added bidirectional delta detection (handles positive and negative signal changes)
    - Implemented EMA smoothing (alpha=0.3) for noise reduction
    - Fixed bar graph display to show absolute delta magnitude
    - Increased calibration samples to 120 for robust baselines
    - Added comprehensive debug output via serial monitor
    - Created CALIBRATION_GUIDE.md with setup and troubleshooting steps
    [code_minimal_test.py, code_v1_multisensor.py, code_v2_multipad.py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]
2025-11-19 Challenge 3: Smart actuator with servo-controlled pinch valve
    - Implemented 3-probe voting sensor system with SG92R servo control
    - Added minimal PWM approach for power stability with external 5V power
    - Features: auto-tracking baselines, detailed LED visualization, hysteresis debouncing
    - Updated Challenge 2 with polarity-agnostic detection and button tuning
    - Added time reports for weeks 6-7
    - Updated development plans and documentation
    [Servo_Test.py, code.py]
2025-11-30 Challenge 3: Fix code errors, add unit tests and documentation
    - Fixed CircuitPython compatibility (OSError instead of FileNotFoundError)
    - Fixed code style issues (line length, exception handling)
    - Updated servo control to use continuous PWM for better reliability
    - Changed probe assignments to A1, A3, A5 (non-adjacent pads)
    - Added comprehensive unit test suite (22 tests covering voting, hysteresis, tracking)
    - Added testing documentation (README_TESTING.md)
    - Added detailed wiring diagram and troubleshooting guide
    - All tests passing
    [code.py, test_code.py]
2025-12-03 Add Motor_Testing project with N20 motor characterization code and Ch4 STL files
    [Drive Plate.stl, N20_motor.stl, N20_motor_mount_2.stl]
2025-12-05 Rename Motor_Testing to Challenge_4 with working motor control and IR remote capability
2025-12-11 Challenge 4: FS90R continuous servo control with IR remote - Implemented servo control using raw PWM - Added IR communication between controller and receiver CPX - Fixed wiring and calibration issues
    [code.py, controller.py]
2025-12-11 Add documentation: EMI charts, SFC diagrams, system maps, tag tables, and workflow documents for Challenges 1-3 and Week 9 time report
    [code.py]
